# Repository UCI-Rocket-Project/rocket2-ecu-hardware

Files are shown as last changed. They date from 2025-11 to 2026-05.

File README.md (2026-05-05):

# rocket2's Engine Control Unit (ECU)
Documenation for ECU is hosted with MKDocs: [Click Here](https://uci-rocket-project.github.io/rocket2-ecu-hardware/)
  
# CAD



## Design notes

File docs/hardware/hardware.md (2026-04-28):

# Hardware Interface
## Electrical Design & 6-Layer Stackup
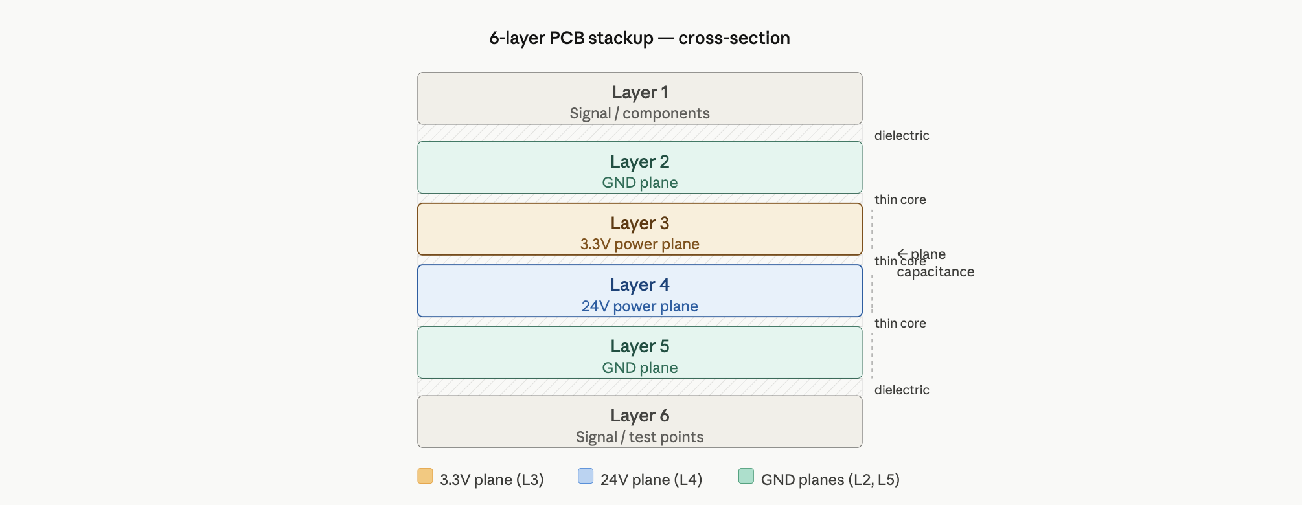
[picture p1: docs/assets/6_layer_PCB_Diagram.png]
ECU Stackup Diagram

*Figure 11: 6-Layer internal routing and power distribution stackup.*

| Layer | Type | Function |
| :--- | :--- | :--- |
| **L1** | Signal/GND | Component landing and logic routing. |
| **L2** | Ground | Solid internal Faraday cage for EMI shielding. |
| **L3** | 3.3V/Signal | Stabilized logic power plane. |
| **L4** | 24V/Signal | High-current propulsion power plane. |
| **L5** | Ground | Lower shielding plane for EM isolation. |
| **L6** | Signal/GND | Bottom-side debug access and telemetry routing. |

**Design :** The proximity of L3 (3.3V) and L4 (24V) to solid GND planes (L2, L5) creates high **inter-planar capacitance**. This acts as a distributed capacitor bank, preventing logic brownouts during high-current valve actuation.

---

## Connectors & Interconnect Board
The system architecture uses a vertical stack to balance high-density I/O with mechanical reliability.

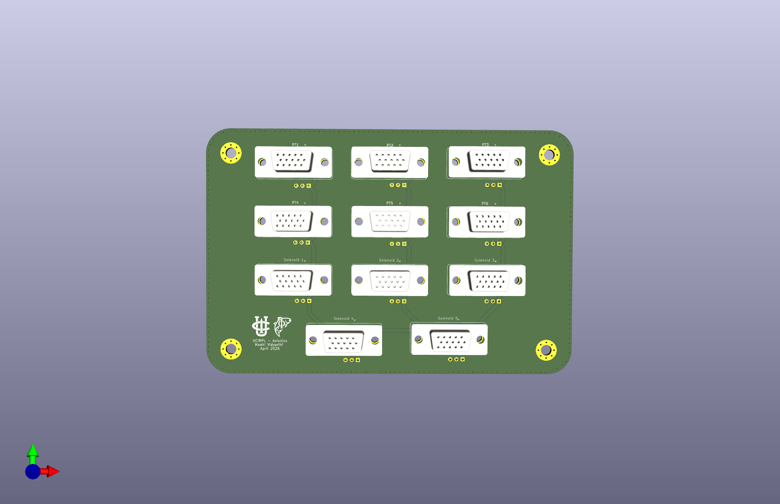
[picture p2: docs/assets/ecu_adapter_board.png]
ECU Adapter Board 3D Render

*Figure 12: 3D Render of the ECU Adapter Board.*

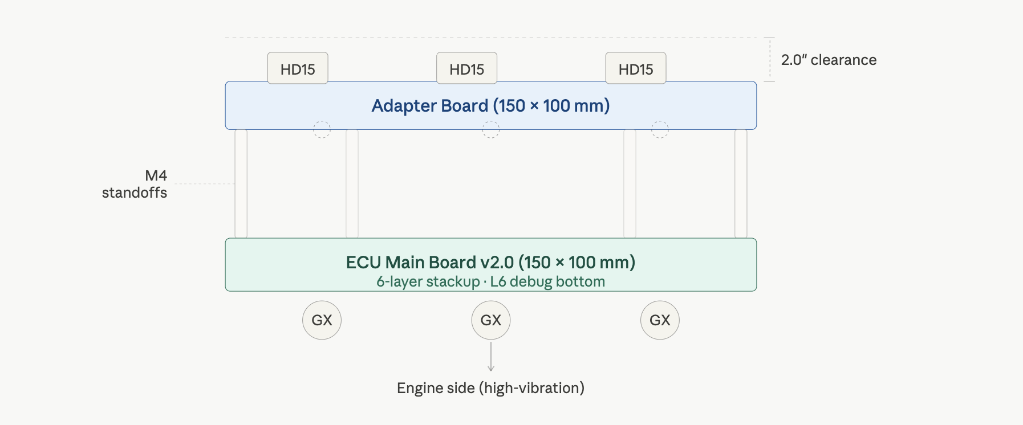
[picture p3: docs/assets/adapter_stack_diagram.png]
ECU Adapter Board 3D Render

*Figure 13: Diagram of the ECU Adapter Board stacking over the main ECU.*

### Transition Strategy: GX to HD15 (DSUB)
* **Main ECU Interface:** Uses **GX-series** circular connectors for high-vibration engine-side connections.
* **Adapter Board:** Stacks via standoffs to convert GX footprints to **HD15 (D-Sub)** for high-density signal distribution to the avionics tray.
* **Legacy Reference:** See [Legacy GX Wiring Documentation](https://github.com/maahividyarthi/ecu-adapter-boards/blob/main/docs/connectors_v1.md) for v1.0 compatibility.

### Mechanical Constraints
| Feature | Dimension | Notes |
| :--- | :--- | :--- |
| **Board Size** | 150mm x 100mm | Matches ECU v2.0 footprint. |
| **Mounting** | 4x M3 Holes | Standardized standoff pattern for vertical stacking. |
| **Max Stack Height**| 2.0" | Combined height of ECU + Standoffs + Adapter Board. |

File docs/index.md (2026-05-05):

# MOCH4 Engine Control Unit (ECU)

---

## System Overview
The Rocket2 ECU is the central flight hardware for the MOCH4 vehicle. It manages power distribution, sensor data acquisition, and valve actuation for the rocket's liquid propulsion system.

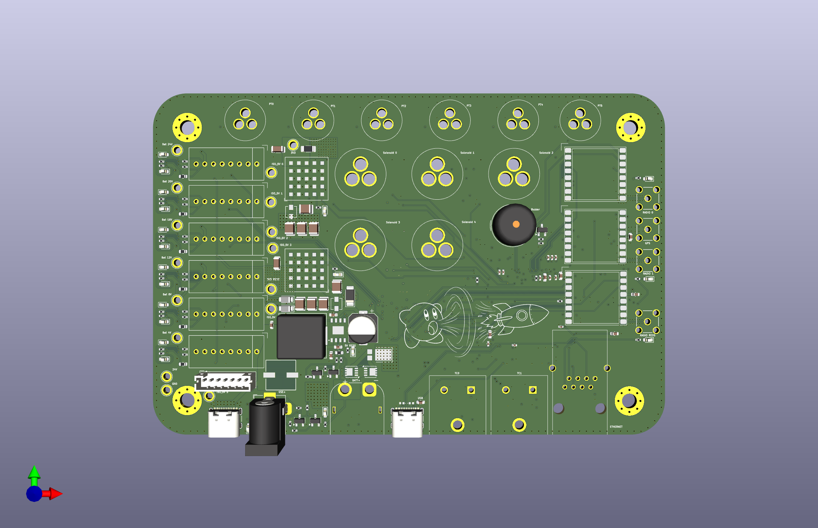
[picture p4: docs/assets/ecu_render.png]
Rocket2 ECU Render

*Figure 1: Top-down render of the Rocket2 ECU v2.0 PCB.*

## Stakeholders
* **AV - Hardware:** Reference for the [6-layer stackup](hardware/hardware.md) signal integrity, [JTAG debugging](bring_up/testplan.md) procedures, and general design logic/justifications.
* **AV - Software:** Mapping for SPI/I2C/UART buses and [STM32 pin assignments](logic/processing.md).
* **Propulsion:** Solenoid limits, actuation behavior, and sensor scaling  
- **Launch Vehicle:** [Mounting specifications](hardware/hardware.md), structural constraints, and connector access.

## Quick Specs
| Parameter | Value | Requirement Reference |
| :--- | :--- | :--- |
| **Input Voltage** | 24V DC | 24V Battery/GSE Requirement |
| **Battery Life** | > 4 Hours | System Operations Window |
| **Logic Level** | 3.3V | STM32 Standard |
| **Mounting Pattern** | 4x M3 holes with 3.2mm clearance | Avionics |
| **Dimensions** | 150mm x 100mm | Fits MOCH4 AV Bay |

## Hardware Architecture & Layout
To ensure flight reliability, the hardware follows a strict isolation and integration strategy:

* **6-Layer Stackup:** Dedicated ground planes (L2, L5) to shield logic (L3) from 24V power noise (L4)[cite: 617, 632]. See [Electrical Design](hardware/hardware.md).
* **Integrated Connectors:** DSUB Connector system implemented through [ECU Adapter Board](hardware/hardware.md) that stacks vertically to ECU, facilitating DSUB Connector to VGA Cable connection.
    * **Deprecated:** Standard HD15 and GX-series connectors are soldered directly to the board to eliminate wire-failure points.
* **Component Zoning:** The Battery Management System (BMS) and regulators are physically isolated on the left side, separated from RF antennas to minimize noise.
* **Accessibility:** All major test points and JTAG headers are accessible from the board's bottom side for post-integration debugging.

## Core Functionality
* **Propulsion:** 5 channels of high-side solenoid switching.
* **Instrumentation:** Dual-redundant [Pressure (PT)](sensors/sensors.md) and [Temperature (TC)](sensors/sensors.md) collection.
* **REDS:** [Emergency depressurization](power/battery_reds.md) capable of switching between Battery and GSE power.
* **Media:** Integrated charging for the onboard Insta360 camera.

## Debug & Failure Modes
* **Visual Feedback:** Onboard LEDs indicate 3.3V rail health and MCU heartbeat.
* **Alarm:** [Integrated siren](actuators/actuators.md) triggers on loss of GSE heartbeat or sensor failure (Note: **NOT IN USE**).
* **Safe State:** All solenoids default to CLOSED on power loss or MCU reset to prevent unintended propellant flow.

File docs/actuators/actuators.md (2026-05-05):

# Actuators & Alarms

## Solenoid Valve Drivers
The ECU features five independent high-side driver channels designed to actuate 24V propulsion solenoids (e.g., PeterPaul Series 20). 

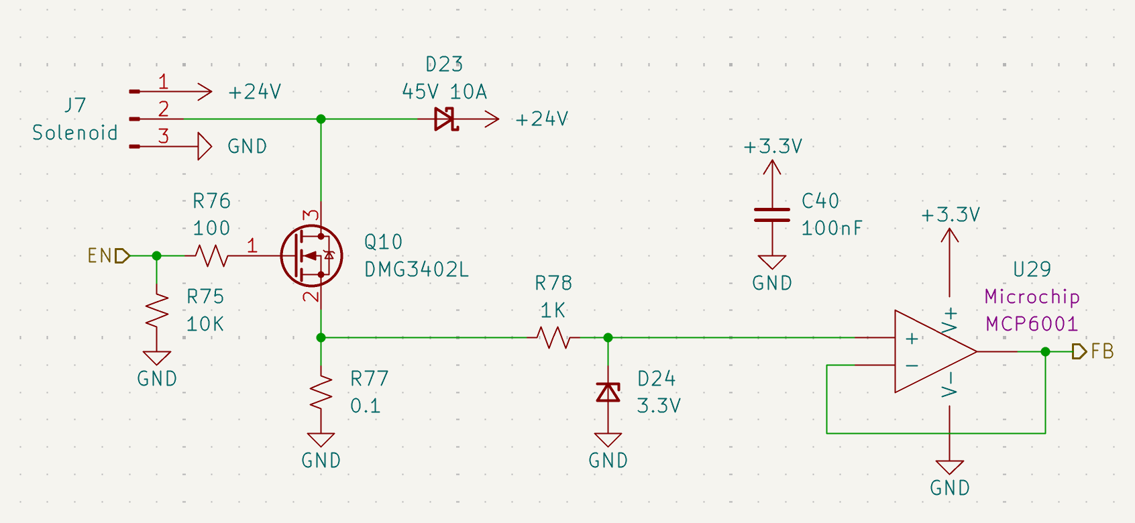
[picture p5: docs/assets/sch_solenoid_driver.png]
Schematic Snippet: Solenoid Driver

*Figure 20: High-side NMOS driver with integrated current feedback.*

### Driver Specifications
* **MOSFET:** [DMG3402L](https://www.diodes.com/assets/Datasheets/DMG3402L.pdf) (N-Channel).
* **Flyback Protection:** A **45V 10A** Schottky diode (**D23**) clamps inductive kickback from the valve coils to prevent rail transients.
* **Safety Logic:** A **10k&Omega;** pulldown resistor (**R75**) ensures the valve remains **CLOSED** if the MCU pin floats during boot or reset.

### Current Feedback (Health Monitoring)

Unlike v1.0, this revision provides active feedback to confirm solenoid actuation.

* **Shunt Resistor:** A **0.1&Omega;** precision resistor (**R77**) placed in the source path translates load current into a small voltage.
* **Protection:** A **3.3V Zener** (**D24**) clamps the feedback signal to protect the MCU ADC.
* **Active Buffer:** An **MCP6001** op-amp (**U29**) buffers the signal, allowing the firmware to distinguish between a healthy firing, an open-circuit (broken wire), or a short-circuit.

---

## Emergency Alarm System: Deprecated
The alarm circuit is designed to provide audible status alerts at the launchpad. 

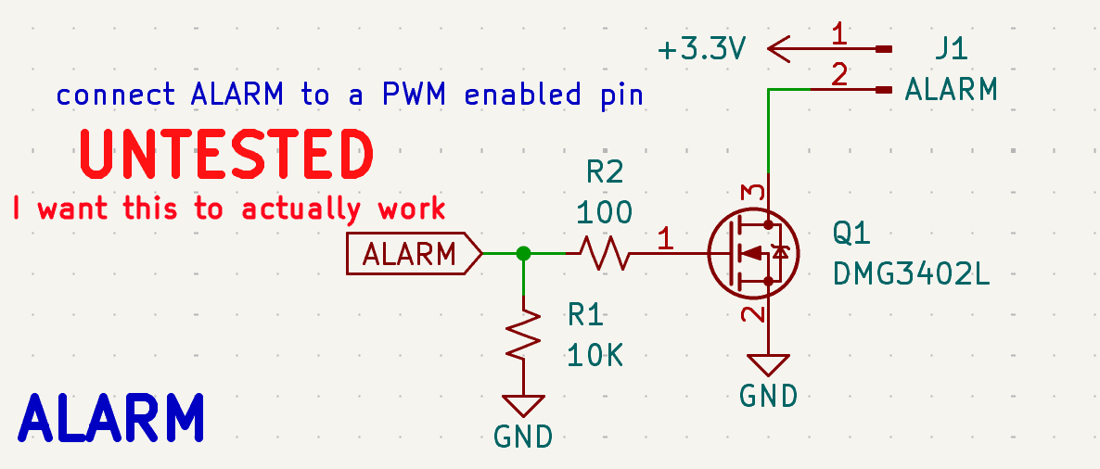
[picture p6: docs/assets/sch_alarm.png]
Schematic Snippet: Alarm Circuit

*Figure 21: Piezo/Siren driver circuit for audible telemetry.*

### Hardware Implementation
* **Driver:** **Q1** ([DMG3402L](https://www.diodes.com/assets/Datasheets/DMG3402L.pdf)) switches the low side of the **J1** alarm header.
* **Power Source:** Tied to the **+3.3V** logic rail.
* **Pin Assignment:** Connected to the **ALARM** net (**PE9**).

### Firmware Requirements (For "Actually Working")
To achieve the desired audible tones, the following software parameters must be met:
1. **PWM Frequency:** Must be tuned to the resonant frequency of the connected piezo (typically **2kHz - 4kHz**).
2. **Duty Cycle:** A **50% duty cycle** is recommended for maximum volume. 
3. **Timer Config:** Pin **PE9** must be configured in Timer Alternate Function mode to allow hardware PWM generation without CPU overhead.

---

## Integration Summary
| Channel | MCU Pin | Function | Notes |
| :--- | :--- | :--- | :--- |
| **SOL0** | PE13 | Vent Valve | NO (Normally Open) |
| **SOL1** | PE14 | Main Fuel | NC (Normally Closed) |
| **SOL2** | PE15 | Main LOX | NC (Normally Closed) |
| **ALARM** | PE9 | Piezo Siren | Deprecated |

**Operational Safety:** All propulsion solenoids are hardware-interlocked to the [REDS Recovery System](../power/battery_reds.md). In a total power loss scenario, the mechanical "Normal" state of the valve is the final fail-safe.

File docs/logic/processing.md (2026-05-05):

# STM32 Processing Core

## System Controller (STM32F469IIT6)
The Rocket2 ECU is powered by an ([STM32F469IIT6](https://www.st.com/resource/en/datasheet/stm32f469ii.pdf)) High-Performance MCU. This controller primarily coordinates sensor data with propulsion actuation logic.

### Power Supply & Decoupling Scheme
To ensure logic stability during high-current solenoid switching, the MCU utilizes an extensive decoupling network.

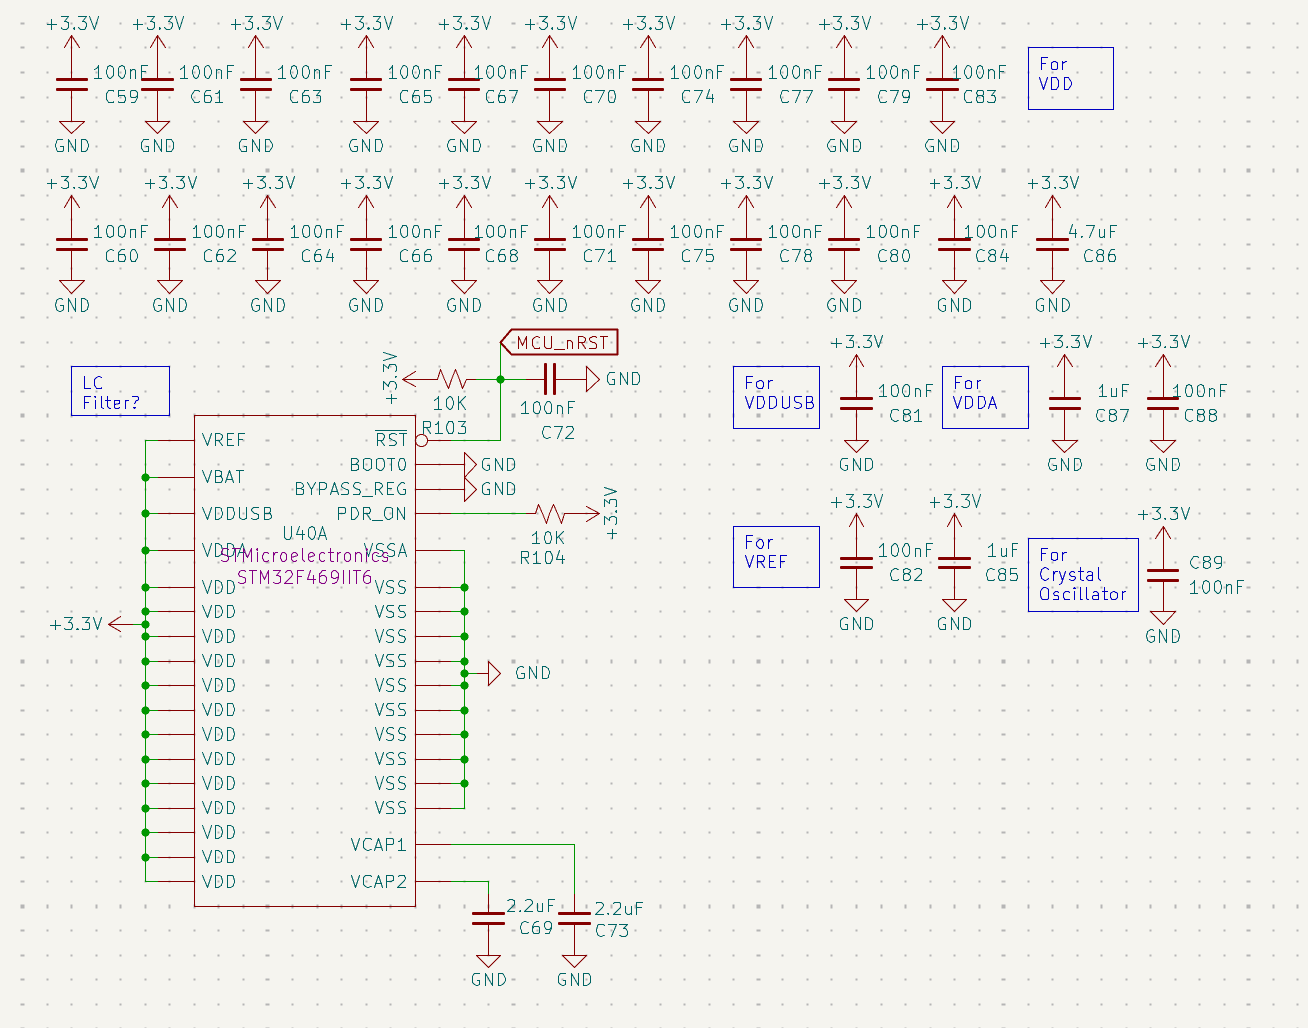
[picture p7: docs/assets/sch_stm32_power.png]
Schematic Snippet: Power Supply Scheme

*Figure 14: STM32 Power Scheme featuring localized 100nF and bulk 4.7&mu;F capacitors.*

* **Core Stability:** Localized **100nF** capacitors are placed at every VDD/VSS pair. 
* **Analog Integrity:** Dedicated decoupling for **VDDA** and **VREF** ensures high-fidelity ADC readings for propulsion and battery sensing.
* **Internal Regulation:** **2.2&mu;F** low-ESR capacitors (**C69, C73**) are utilized on the **VCAP1/VCAP2** pins to stabilize the internal 1.2V core voltage.

---

## Debug & Programming Interfaces
The board provides two primary methods for firmware deployment and real-time telemetry debugging.

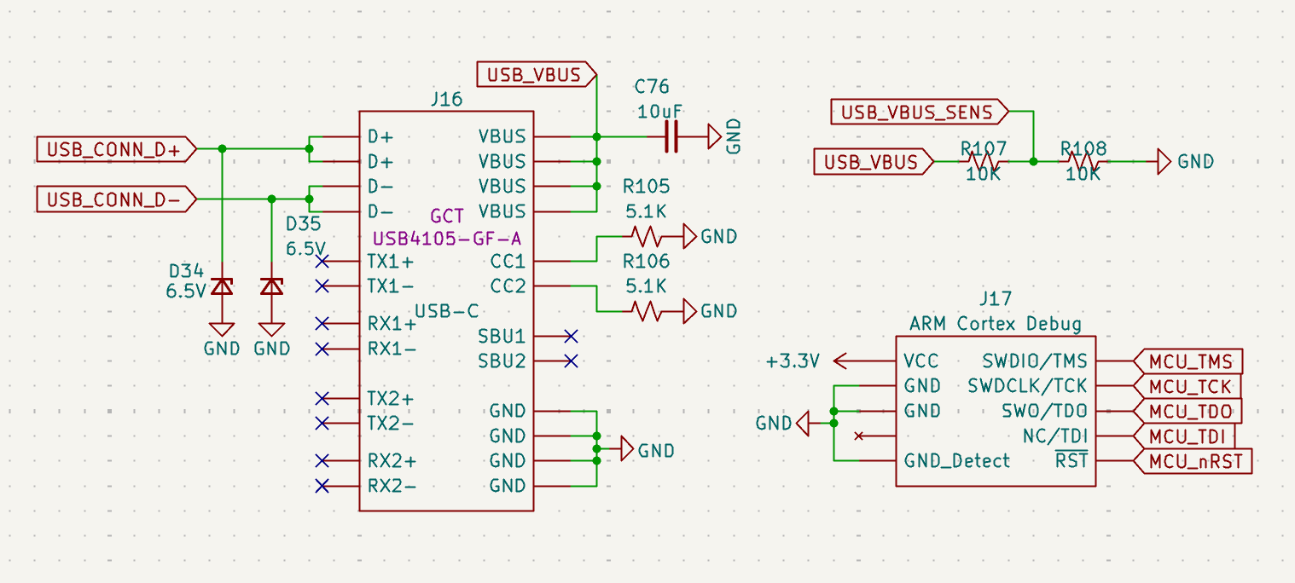
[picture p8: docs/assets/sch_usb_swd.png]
Schematic Snippet: USB-C and SWD

*Figure 15: USB-C interface and ARM Cortex 10-pin JTAG/SWD header.*

### SWD (Serial Wire Debug)
The **J17** header utilizes the standard **ARM Cortex 10-pin** (2x5) 1.27mm pitch layout.

* **Signals:** SWDIO, SWCLK, and SWO are routed for real-time instruction tracing.
* **Reset:** The **MCU_nRST** line is tied to a **100nF** capacitor (**C72**) and a **10k&Omega;** pull-up to prevent accidental resets from EMI.

### USB-C Interface
* **Model:** GCT USB4105-GF-A (16-pin).
* **Protection:** D34 and D35 (6.5V TVS diodes) protect the high-speed data lines from ESD during handling.
* **Sensing:** A voltage divider (**R107/R108**) on the **USB_VBUS_SENS** line allows the MCU to detect when a ground station is connected via USB.

---

## Peripheral Pin Mapping
The following table outlines the functional mapping of the MCU GPIOs. The detailed ioc file and firmware documentation will be in the rocket2-ecu-firmware repo.

| Peripheral Group | Pin | Signal Name | Function |
| :--- | :--- | :--- | :--- |
| **Actuation** | PE13-15, PG0-1 | `SOLENOID[0-4]_EN` | PWM/Logic Valve Drive |
| **Feedback** | PB0-2, PC4-5 | `SOLENOID[0-4]_FB` | Analog Current Sensing |
| **Instrumentation** | PC0-3, PA2 | `PT[1-5]` | Pressure Transducer Inputs |
| **BMS Status** | PD8-12 | `REDs_CH[0-4]` | Isolated Charging Status |
| **Telemetry** | PF0-PF9 | `RADIO[0-1]` | Dual-LoRa SPI/GPIO Bus |
| **Flight Sensors** | PG9-14 | `IMU_SPI6` | High-speed IMU Acquisition |
| **Status** | PG5 | `STATUS_LED` | Heartbeat LED (D36) |

---

## Flash Memory Architecture
The ECU features a dual-chip external storage configuration providing a total of **2GB (1Gb + 1Gb)** of non-volatile memory. This high-capacity array is dedicated to high-frequency data logging and state persistence during flight.

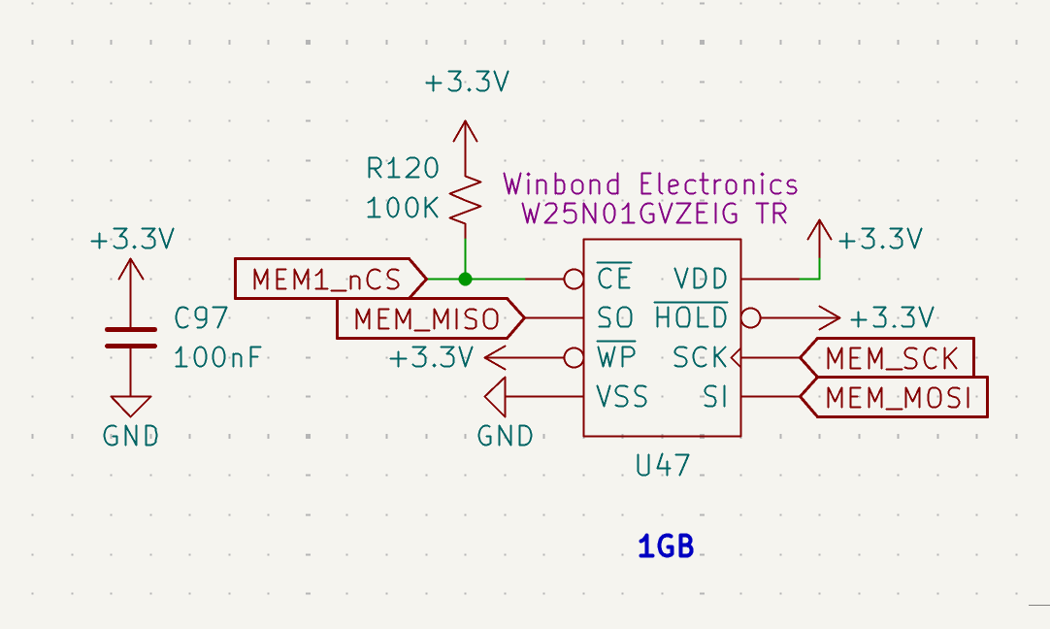
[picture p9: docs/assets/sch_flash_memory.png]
Schematic Snippet: Flash Memory Architecture

*Figure 16: Winbond W25N01G High-Performance Serial NAND Flash interface.*

* **Model:** [Winbond W25N01GVZEIG TR](https://www.winbond.com/resource-files/w25n01gv%20revl%20050918%20unsecured.pdf) (1G-bit / 128MB per chip).
### Hardware Configuration
* **Model:** Winbond **W25N01GVZEIG TR** (1G-bit / 128MB per chip).
* **Bus Interface:** Utilizes a high-speed **SPI** bus (`MEM_SCK`, `MEM_MISO`, `MEM_MOSI`).
* **Active-Low Select:** The chip-enable line (**MEM_nCS**) is tied to a **100k&Omega;** pull-up resistor (**R119**) to ensure the memory remains deselected during MCU reset, preventing data corruption.
* **Write Protection:** The **WP** (Write Protect) and **HOLD** pins are hardwired to **+3.3V** to allow continuous high-speed write access during flight.

### Data Logging Strategy
* **Total Capacity:** 2GB.
* **Throughput:** Optimized for the STM32's maximum SPI clock frequency to ensure that 100Hz+ sensor polling does not experience "blocking" during write cycles.
* **Decoupling:** Each IC is supported by a **100nF** decoupling capacitor (**C96**) placed immediately adjacent to the VDD pin to maintain signal integrity during high-speed switching.

---

### Fail-Safe Execution
* **Default States:** All solenoid enable pins are hardware-referenced to GND, ensuring valves remain in a safe/closed state during an MCU power loss or reset event.

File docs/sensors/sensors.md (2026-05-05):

# Sensors

## Flight Sensors
The ECU utilizes a multi-sensor architecture for real-time orientation and altitude tracking. 

| Sensor | Model | Bus | Range |
| :--- | :--- | :--- | :--- |
| **IMU** | [BMI088](https://www.bosch-sensortec.com/media/boschsensortec/downloads/datasheets/bst-bmi088-ds001.pdf) | SPI | ±24g / ±2000°/s |
| **Magnetometer**| [BMM350](https://www.bosch-sensortec.com/media/boschsensortec/downloads/datasheets/bst-bmm350-ds001.pdf) | I2C |  ±2000μT |
| **Altimeter** | [MS5607](https://www.te.com/commerce/DocumentDelivery/DDEController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) | SPI | 10–1200 mbar |

### Magnetometer (BMM350)
The BMM350 replaces the deprecated BMM150. It provides improved resolution (0.1μT) and a higher max sampling rate (400Hz).

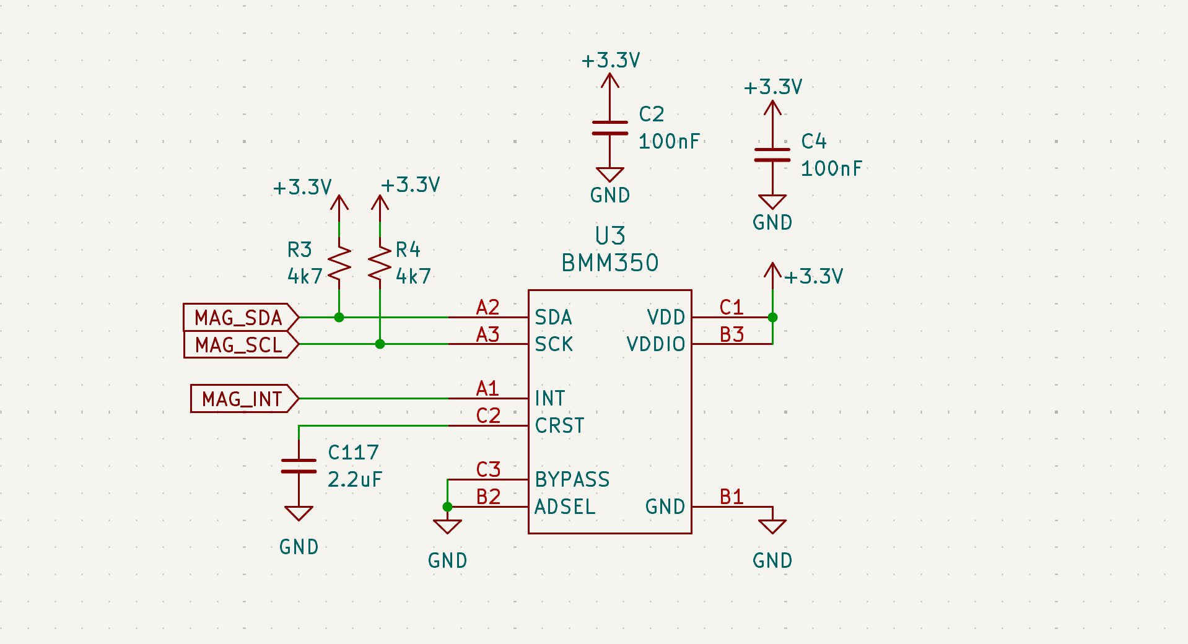
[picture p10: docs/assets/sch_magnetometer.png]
Schematic Snippet: Magnetometer

*Figure 23: BMM350 I2C interface with 4.7kΩ pull-up resistors (R3, R4).*

### IMU (BMI088)
Utilizes SPI for deterministic data acquisition. Provides ±24g acceleration range and ±2000°/s rate sensing.

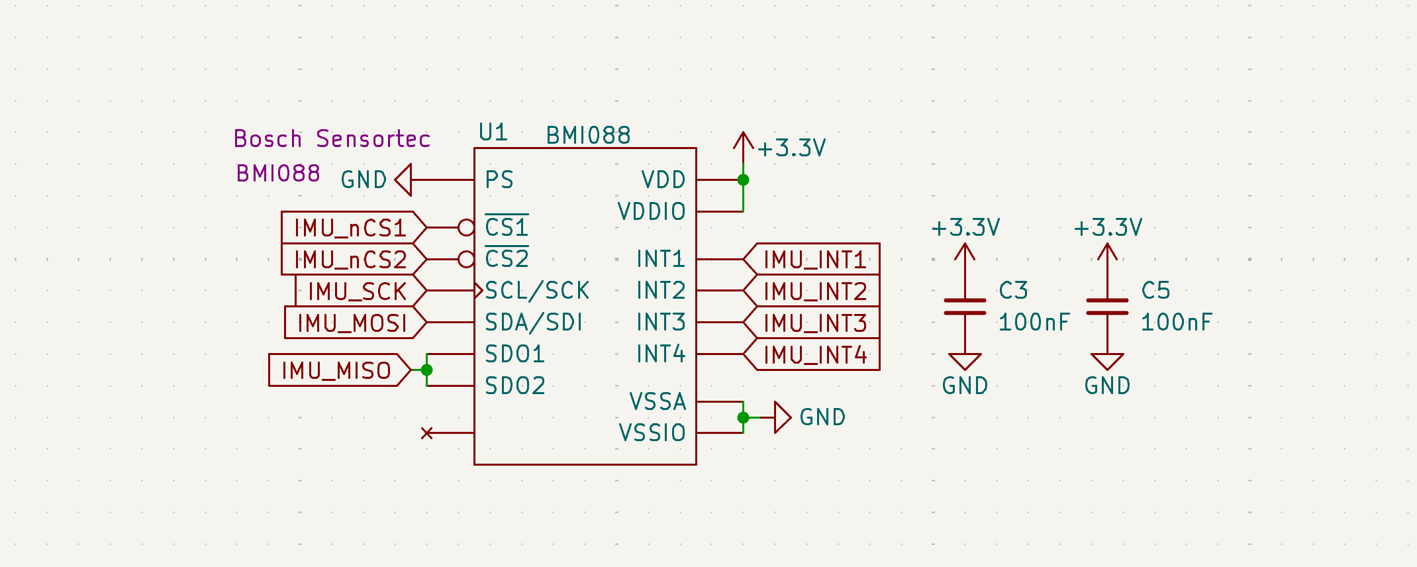
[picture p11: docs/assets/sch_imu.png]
Schematic Snippet: IMU

*Figure 24: BMI088 SPI interface with independent Accel and Gyro Chip Selects.*

### Altimeter (MS5607)
The Altimeter is connected via SPI, schematic attached below.

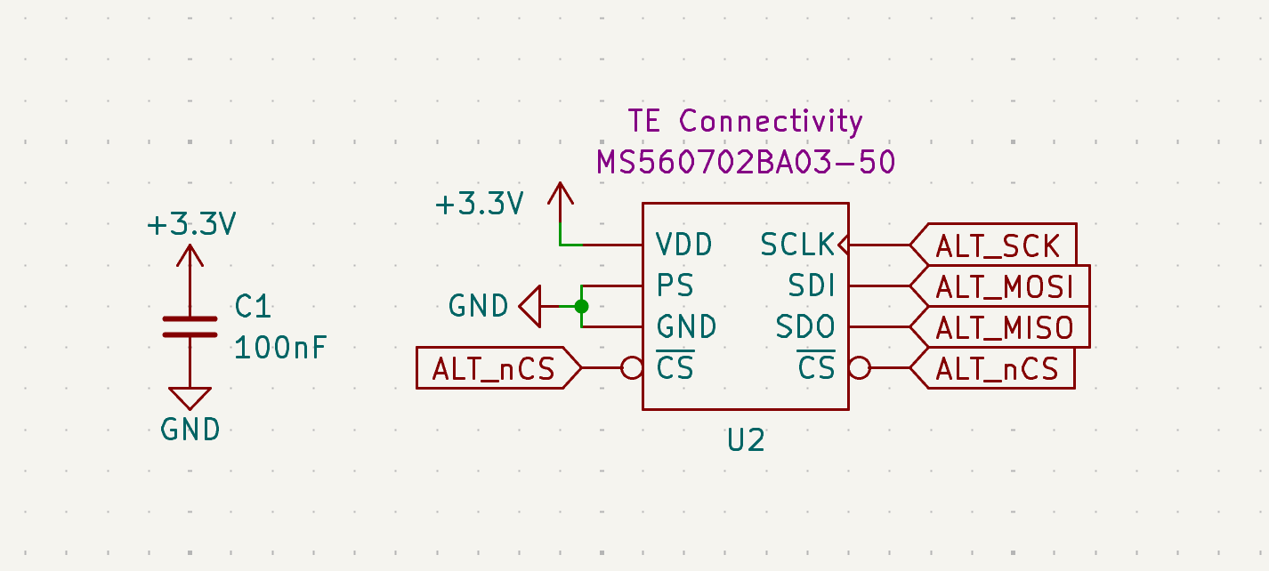
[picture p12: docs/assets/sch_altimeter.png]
Schematic Snippet: Altimeter

*Figure 25: MS5607 SPI interface with localized decoupling capacitors.*

---

## Propulsion Sensors
Propulsion sensors are subject to high EMI and vibration. Therefore, signal conditioning and filtering are critical for data integrity.

### Pressure Transducers (PT)
The PT circuit translates 0–5V analog signals from the transducer down to a 0–3.3V range suitable for the STM32 ADC.

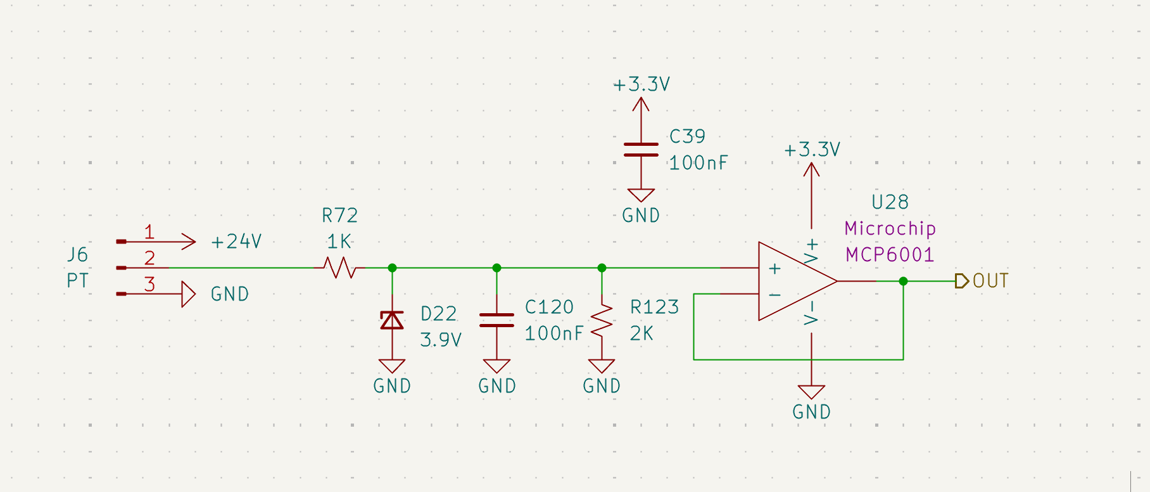
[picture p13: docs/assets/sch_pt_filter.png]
Schematic Snippet: PT Signal Conditioning

*Figure 26: PT conditioning stage featuring voltage clamping and active buffering.*

* **Sensor Model:** [Transducers Direct TDH40](https://transducersdirect.com/products/pressure-transducers/standard-pressure-transducers/tdh40-pressure-transducer-low-price-high-accuracy-volume-discount/)
* **Voltage Divider & Clamping:** A 1kΩ (**R72**) and 2kΩ (**R123**) divider scales the signal. A 3.9V Zener (**D22**) provides overvoltage protection.
* **Active Buffer:** An **MCP6001** op-amp (**U28**) provides a low-impedance input to the ADC to prevent sampling errors.
* **Noise Filtering:** An integrated RC lpf (**R72, C120**) provides a cutoff frequency of **1591 Hz** to reject high-frequency valve and engine noise.

### Thermocouples (TC)
Uses the **MAX31855JASA+** cold-junction compensated converter.

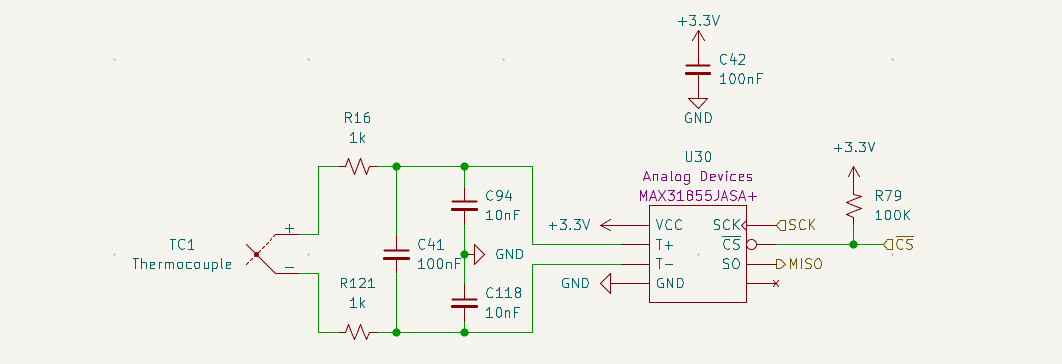
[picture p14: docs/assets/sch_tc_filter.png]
Schematic Snippet: Thermocouple Interface

*Figure 27: TC front-end with optimized differential and common-mode filtering.*

#### Filter Design & Justification
The TC front-end uses an optimized RC filter network to reject common-mode noise while maintaining a high signal-to-noise ratio (SNR). The design adheres to the **C<sub>diff</sub> > 10 &times; C<sub>cm</sub>** rule to minimize the impact of component tolerances on noise rejection.

| Parameter | Value | Formula / Calculation |
| :--- | :--- | :--- |
| **Series Resistance (R)** | 1 k&Omega; | R16, R121 |
| **Diff. Capacitance (C<sub>diff</sub>)** | 100 nF | C41 |
| **Common Mode Cap (C<sub>cm</sub>)** | 10 nF | C94, C118 |
| **Diff. Mode Cutoff (f<sub>c,dm</sub>)** | **~758 Hz** | 1 / (2&pi; &times; 2R &times; (C<sub>diff</sub> + C<sub>cm</sub>/2)) |
| **Common Mode Cutoff (f<sub>c,cm</sub>)** | **~15.9 kHz** | 1 / (2&pi; &times; R &times; C<sub>cm</sub>) |

* **Common Mode Rejection:** 10nF common-mode capacitors (**C94, C118**) reject noise that applies equally to both TC high and low voltages.
* **Sampling Sync:** The ~758Hz differential cutoff is specifically tuned to reject high-frequency engine noise while maintaining the 14Hz sampling resolution of the MAX31855.

---

### Integration & Cabling Note
As documented in the [Hardware Interface](../hardware/hardware.md), the connector system has been upgraded from direct-to-GX soldering to a standardized DSUB to VGA cable system. This system has been implemented for the ECU throught ECU Adaper Board, and will interface on the physical sensor end with a **Universal Adapter Board** system as described below. 

* **Sensor End:** PT/TC connects to a slot on the Universal Adapter Board.
* **Cable:** Standard VGA cables with **HD15 (D-Sub)** connectors are used for the main cable run.
* **ECU End:** Cable connects to the **ECU Adapter Board** stacked on the main ECU, completing the electrical path to the conditioned ADC pins.

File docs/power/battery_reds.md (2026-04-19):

# Battery & REDS 

## Overview
The **REDS** (Recovery Event Driver System) is a safety-critical power hub. It provides an isolated environment for 6-cell battery charging, precise rail monitoring via buffered dividers, and high-side switching for propulsion vent valves. 

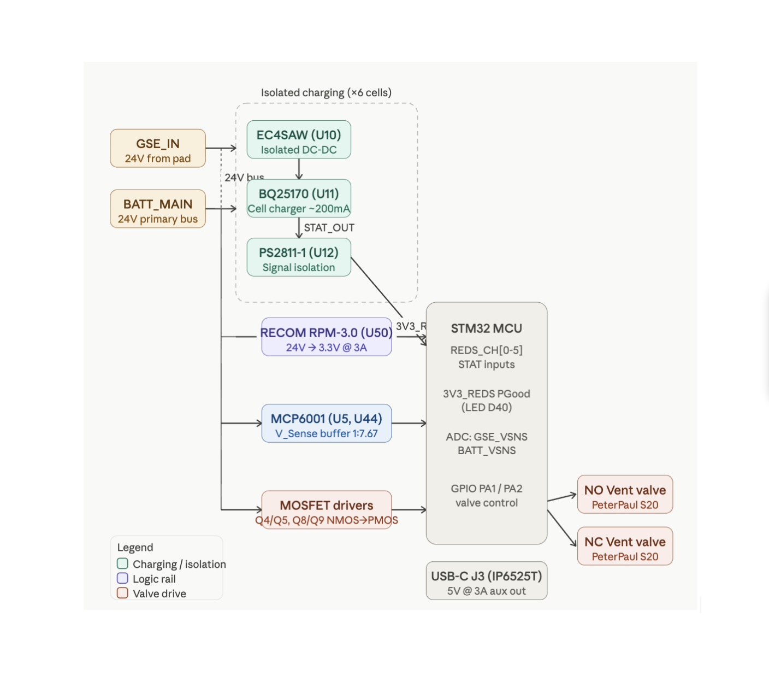
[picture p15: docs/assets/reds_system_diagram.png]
REDS System Architecture

*Figure 4: High-level block diagram of charging isolation and recovery logic.*

## Stakeholder Relevance
* **Avionics:** Critical facet of power on electronics; ensures logic survival during high-current events.
* **Propulsion:** Drive capacity for [PeterPaul Series 20](https://www.peterpaul.com/valves/2-way-normally-opened/series-20-model-21) (NO/NC) vent valves.
* **Operations:** Pre-launch camera power and battery health monitoring.

---

## Power System Reference
| Net Name | Source | Nominal Voltage | Max Current | Notes & Hardware Specs|
| :--- | :--- | :--- | :--- | :--- |
| **GSE+** | Ground pad | 24V | 5A* | External input used at pad. |
| **BATT_MAIN+** | 6S LiPo | 22.2V - 25.2V | — | Primary vehicle battery bus. |
| **GND** | Ground | 0V | — | Reference for ECU logic and valve returns. |
| **ISO_5V** | Cincon EC4SAW | 5V | 600mA | Isolated supply per charging block; floats relative to cell GND. |
| **ISO_GND** | Cincon EC4SAW | — | — | **Isolated return**; MUST NOT be shorted to System GND. |
| **3V3_REDS** | [RECOM RPM-3.0](https://www.recom-power.com/pdf/Innoline/RPM-6.0.pdf) | 3.3V | 3A | Independent logic rail; survives primary ECU bus failure. |
| **3V3_MAIN** | ECU Buck Reg | 3.3V | — | Primary logic rail for non-recovery ECU functions. |
| **GSE_VSNS** | [MCP6001](https://ww1.microchip.com/downloads/en/DeviceDoc/MCP6001-1R-1U-2-4-1-MHz-Low-Power-Op-Amp-DS20001733L.pdf) | 0&ndash;3.3V | — | Buffered ADC signal scaling GSE+ rail (1V:7.67V). |
| **BATT_VSNS** | [MCP6001](https://ww1.microchip.com/downloads/en/DeviceDoc/MCP6001-1R-1U-2-4-1-MHz-Low-Power-Op-Amp-DS20001733L.pdf) | 0&ndash;3.3V | — | Buffered ADC signal scaling BATT_MAIN+ (1V:7.67V). |
| **5V0_REDS** | [IP6525T](https://html.alldatasheet.com/html-pdf/1131972/INJOINIC/IP6525T/458/1/IP6525T.html) | 5V | 3A | Aux rail for Insta360; sourced from GSE+ via D3. |
| **STAT_OUT[0-5]** | [PS2811-1](http://www.vishay.com/docs/81753/vo615a.pdf) | 3.3V Logic | — | Isolated charge status (Active-Low) from BQ25170. |

## Design Details

### 1. Isolated Charging Architecture
To prevent ground loops and cell-balance shorts during charging, the system utilizes 6 independent charging blocks.

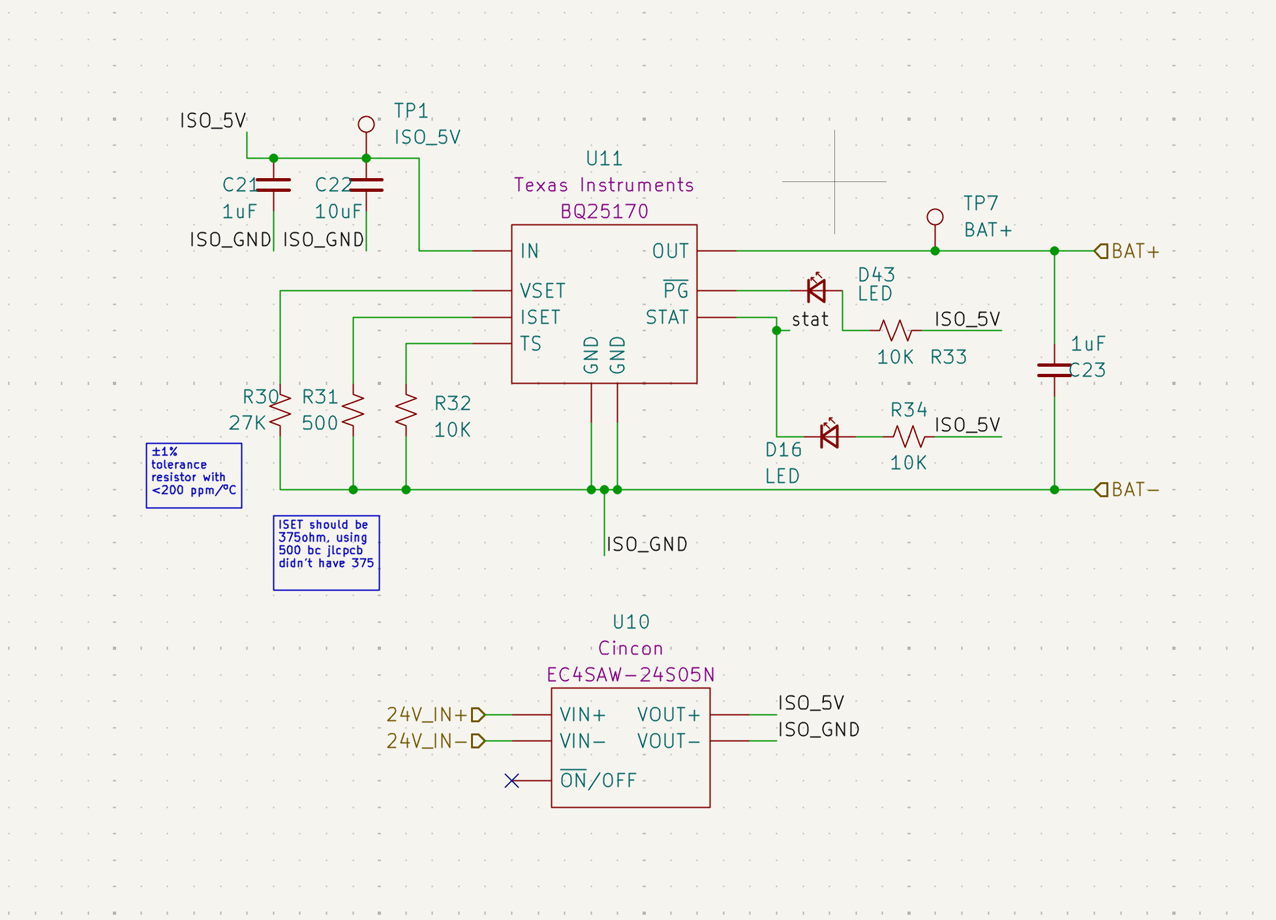
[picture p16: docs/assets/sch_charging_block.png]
Schematic Snippet: BQ25170 Charging Block

*Figure 5: Isolated charging stage showing Cincon DC-DC and BQ25170.*

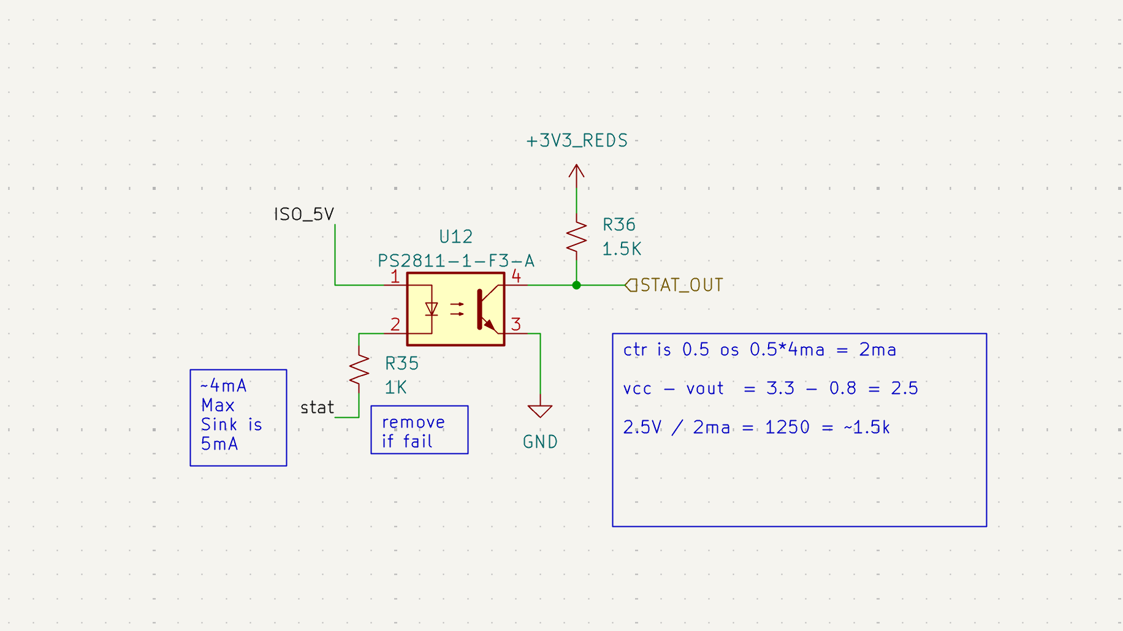
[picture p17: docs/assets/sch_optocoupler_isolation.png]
Schematic Snippet: Optocoupler Interface

*Figure 6: Isolated status feedback via PS2811-1 Optocouplers.*

* **Power Isolation:** Each cell uses a **Cincon EC4SAW (U10)** to decouple the GSE power from the specific battery cell potential.
* **Signal Isolation:** `STAT_OUT` signals use [PS2811-1](http://www.vishay.com/docs/81753/vo615a.pdf) optocouplers (U12) to cross the isolation barrier to the 3.3V logic rail. 
* **Design Deviation (ISET):** Target I_SET was 375 &Omega;. Current assembly uses **500 &Omega;** (&plusmn;1%, &lt;200 ppm/&ordm;C) due to availability, resulting in a slightly lower, safer charge rate for the [BQ25170](https://www.ti.com/product/BQ25170).

### 2. 3.3V_REDS Logic Rail
The `3V3_REDS` rail is independent of the main ECU 3.3V bus to ensure recovery capability  during bus failures.

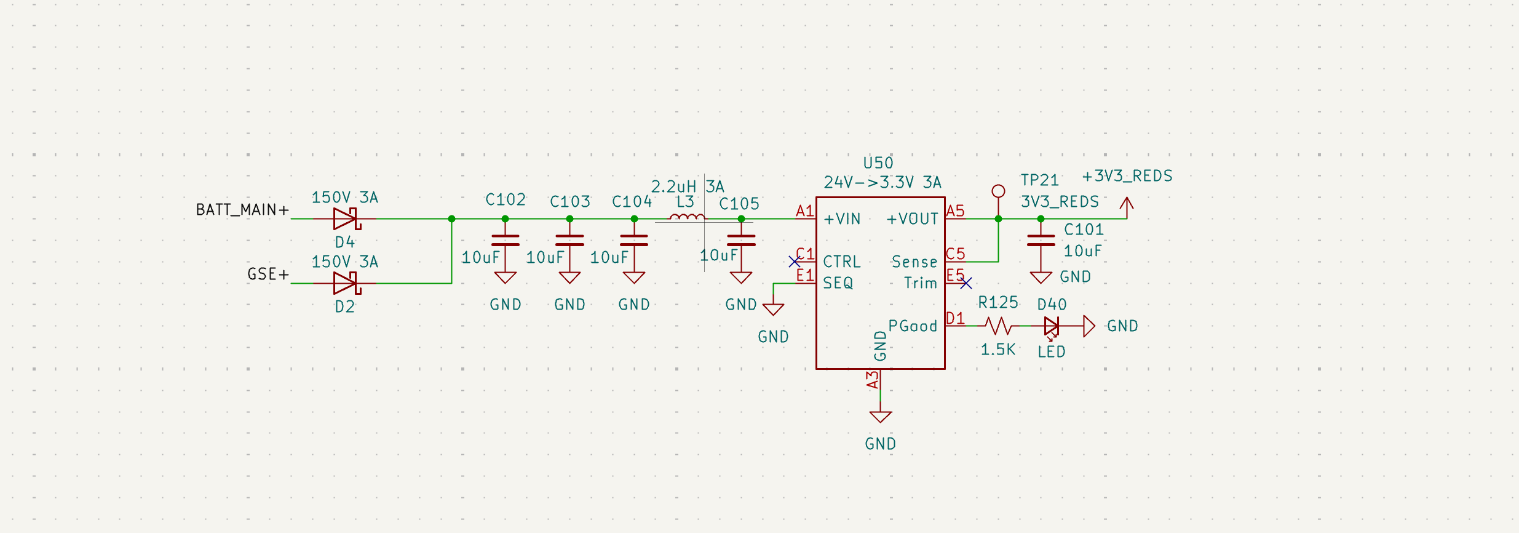
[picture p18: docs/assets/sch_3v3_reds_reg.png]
Schematic Snippet: U50 Regulator

*Figure 7: U50 RECOM regulator stage with input Pi-filter.*

* **Regulator:** **U50** ([RECOM RPM-3.0](https://www.recom-power.com/pdf/Innoline/RPM-6.0.pdf)) 24V to 3.3V.
* **Input Pi-Filter:** L3 (2.2 &mu;H) and C102-104. 
* **Thermal Note:** Inductor **L3** is rated for **3A**. While the RECOM module is robust, L3 is the primary thermal bottleneck if draw exceeds 3A.

### 3. Rail Voltage Sensing (MAIN & REDS)
The ECU employs two identical dual-stage sensing circuits to monitor the health of the 24V GSE and Battery rails for both the primary ECU (MAIN) and REDS.

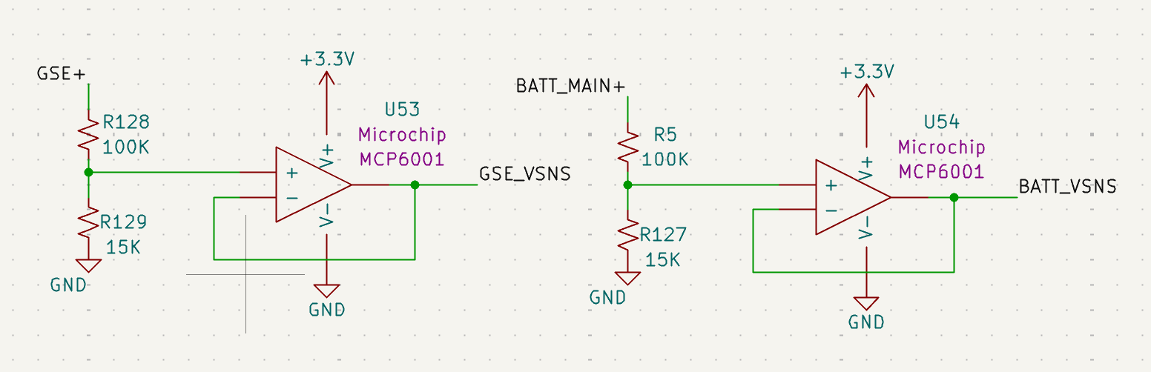
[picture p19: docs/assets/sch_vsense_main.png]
Schematic Snippet: V_Sense MAIN

*Figure 8: V_Sense MAIN buffers (U53/U54) monitoring primary power rails.*

* **Circuit Identity:** The REDS sensing stage (U5/U44) is topologically identical to the MAIN stage (U53/U54) shown above.
* **Precision Divider:** A 100 k&Omega; / 15 k&Omega; network provides a 1V : 7.67V scaling ratio.
* **High-Impedance Buffering:** [MCP6001](https://ww1.microchip.com/downloads/en/DeviceDoc/MCP6001-1R-1U-2-4-1-MHz-Low-Power-Op-Amp-DS20001733L.pdf) Op-amps are configured as voltage followers. This ensures that the sensing network does not load the battery and prevents ADC input impedance from introducing measurement error.
* **Component Requirement:** Resistors must be &plusmn;1% tolerance or better to ensure measurement accuracy across the flight temperature envelope.

### 4. Valve Drive Circuitry
The board features two high-side MOSFET driver channels (Q4/Q5 and Q8/Q9) designed to drive solenoids.

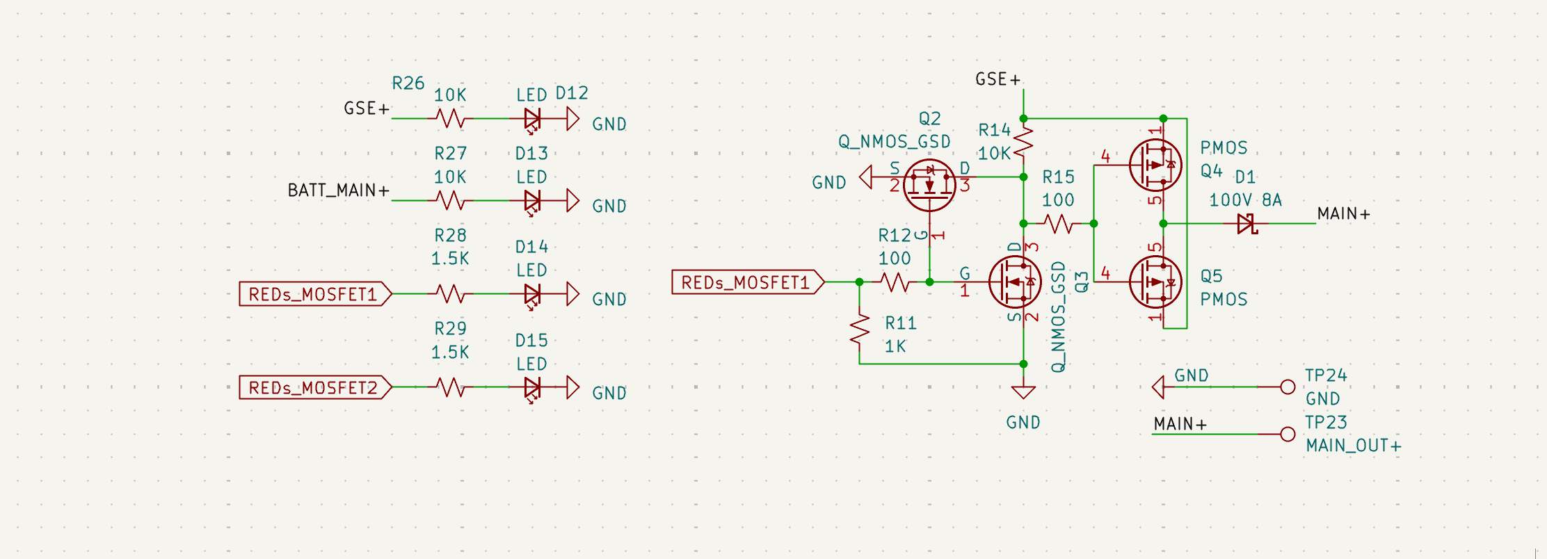
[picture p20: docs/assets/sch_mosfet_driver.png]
Schematic Snippet: MOSFET Drivers

*Figure 9: Typical NMOS-to-PMOS level shifting for 24V valve control (Channel 1 shown).*

* **Topology:** NMOS-to-PMOS level shifting (3.3V to 24V).
* **Flyback Protection:** Integrated 100V 8A Schottky diodes (D1, D7) clamp inductive spikes from solenoids.
* **Safety Logic:** NMOS pulldowns ensure valves remain in their "Normal" state if logic pins float.

### 5. Insta360 Camera 
A dedicated high-current 5V rail is provided for external peripherals, primarily the Insta360 flight camera.

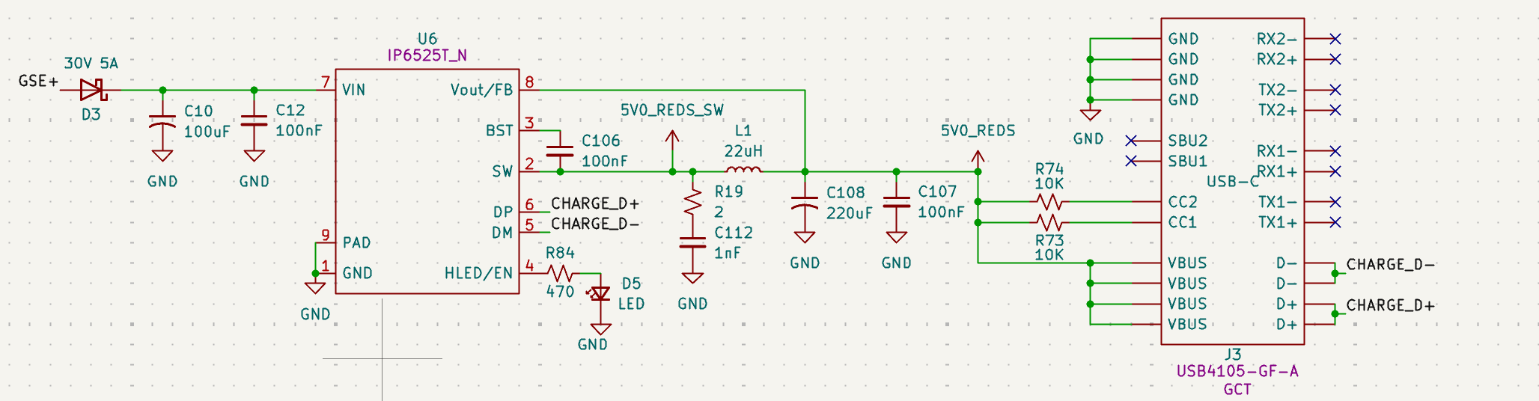
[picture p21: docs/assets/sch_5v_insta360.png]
Schematic Snippet: 5V 3A Insta360

*Figure 10: IP6525T Step-down converter for USB-C power delivery.*

* **Regulator:** **U6** ([IP6525T](https://html.alldatasheet.com/html-pdf/1131972/INJOINIC/IP6525T/458/1/IP6525T.html)) provides a stable 5V output at up to 3A.
* **Power Source:** This rail is tied to **GSE+** via a 30V 5A Schottky diode (**D3**). 
* **Ops Note:** Ops must verify the camera switches to internal battery smoothly during disconnect to ensure recording does not stop at T-0.
* **Filtering:** A 22 &mu;H inductor (**L1**) and a bulk 220 &mu;F capacitor (**C108**) minimize switching ripple to prevent video artifacts.
* **Indicator:** **LED D5** (Green) indicates the 5V Aux rail is active.

---

## Hardware&ndash;Software Interface

### Optocoupler Logic Calculation
The pull-up resistor (R36) for the `STAT_OUT` signal is **1.5 k&Omega;**.
* **CTR Calculation:** * V_{CC} - V_{OUT} = 3.3V - 0.8V = 2.5V
    * 2.5V / 2mA = 1250 &Omega; &approx; **1.5 k&Omega;**
* **Diagnostic:** If status signals fail to toggle, verify the optocoupler is driving at least 2mA.

## Errata / Revision Notes
* **Diode Corrected:** Fixed orientation of 30V 2A diode (reversed in v1.0).
* **ADC Simplification:** Deleted ADC from schematic for charge status; routed charging status to main ECU MC.

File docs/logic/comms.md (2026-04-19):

# Telemetry & Communications

## Dual LoRa Radio Modules (RFM95W)
The system utilizes two independent LoRa modules to provide long-range, low-power telemetry links at 915 MHz.

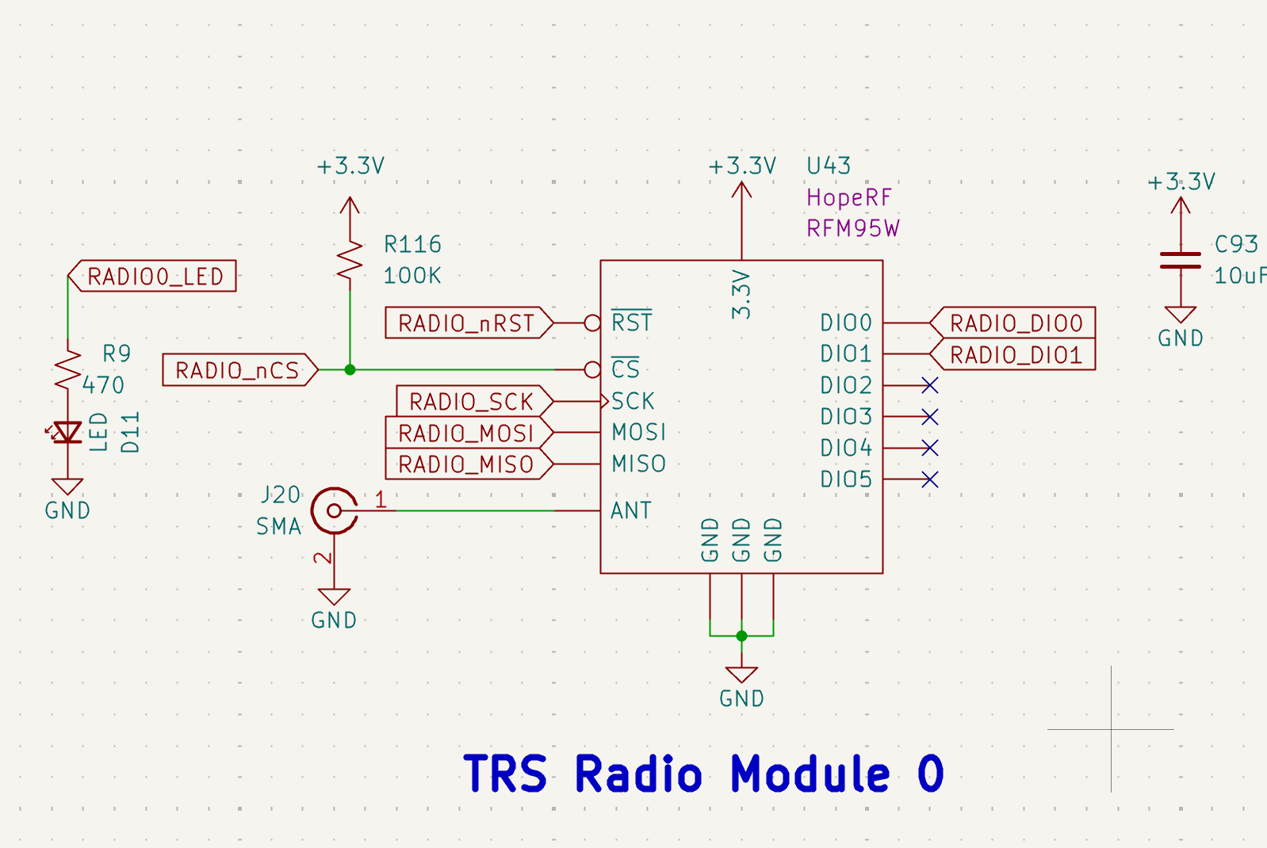
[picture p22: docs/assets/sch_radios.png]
Schematic Snippet: Dual Radio Modules

*Figure 17: Redundant TRS Radio Modules 0 and 1.*

* **Model:** [HopeRF RFM95W](https://cdn.sparkfun.com/assets/learn_tutorials/8/0/4/RFM95_96_97_98W.pdf).
* **Interface:** Connected via high-speed **SPI** with dedicated Chip Selects (**RADIO_nCS**, **RADIO1_nCS**).
* **Indicators:** Visual status is provided by **D11** and **D39** LEDs, which trigger during active packet transmission.
* **Antenna:** Standard 50&Omega; SMA connectors (**J20, J22**) are utilized for external dipole or whip antennas.
* **Design Defense:** Dual modules allow for frequency hopping or redundant data streams, ensuring telemetry persists even if one antenna path is compromised.

---

## GNSS Navigation (u-blox ZOE-M8Q)
For absolute positioning and time-synchronization, the ECU features a high-sensitivity u-blox GNSS module.

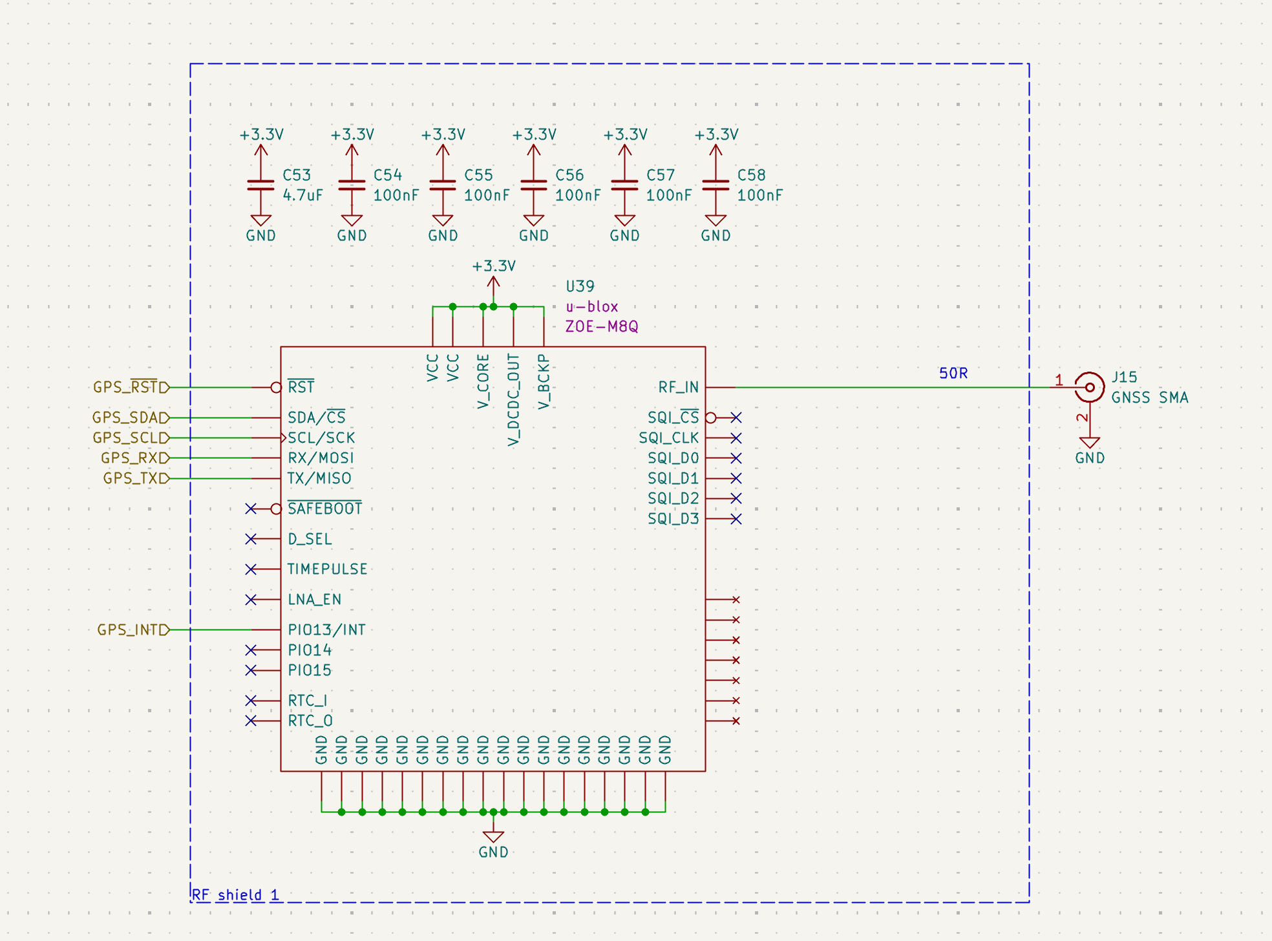
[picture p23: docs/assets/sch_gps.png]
Schematic Snippet: GPS/GNSS Module

*Figure 18: ZOE-M8Q implementation with RF shielding and active filtering.*

* **Model:** [u-blox ZOE-M8Q](https://content.u-blox.com/sites/default/files/ZOE-M8_DataSheet_UBX-16008094.pdf).
* **EMI Protection:** The module is housed within a dedicated **RF Shield** to prevent internal ECU logic noise from desensitizing the GPS receiver.
* **Interface:** Connected via **UART** (**GPS_RXD/TXD**) for standard NMEA sentence parsing.
* **Antenna:** Fed through a **50&Omega;** microstrip to an SMA connector (**J15**) for external active/passive GPS antennas.

---

## Ground-Test Ethernet (Grid Connect XPort)
A hardwired Ethernet interface is provided for high-bandwidth data offloading and ground station commanding during pad operations.

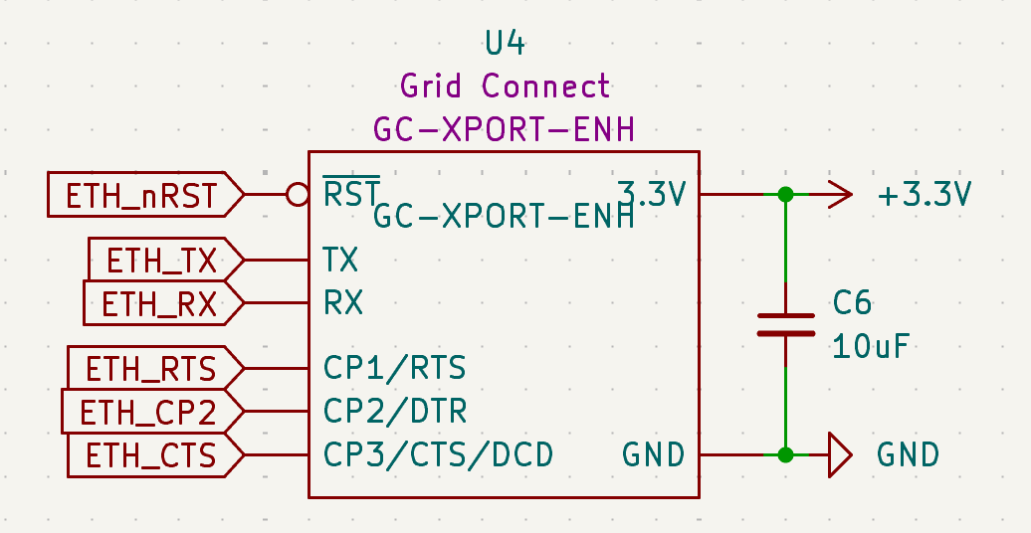
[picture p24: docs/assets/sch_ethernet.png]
Schematic Snippet: Ethernet Interface

*Figure 19: GC-XPORT-ENH Serial-to-Ethernet implementation.*

* **Model:** [Grid Connect GC-XPORT-ENH](https://gridconnect.box.com/shared/static/bu8k99agcgg8gspnja0ca8w7647gfghh.pdf).
* **Protocol:** Functions as a Serial-to-Ethernet bridge, allowing the STM32 to communicate over TCP/UDP via its internal USART interface.
* **Stability:** Utilizes a **10uF** decoupling capacitor (**C6**) to stabilize the 3.3V rail during high-speed data bursts.
* **Control:** The **ETH_nRST** line allows the MCU to power-cycle the module if a network hang is detected.

---

## Communication Fail-Safes
* **Independent Resets:** Both LoRa radios and the Ethernet module have discrete reset lines tied to the MCU, preventing single peripheral hang from locking the communication bus.
* **EMI Zoning:** All RF connectors (SMA) are positioned at the board edge, away from the 24V propulsion regulation zone, to maximize signal-to-noise ratio (SNR).

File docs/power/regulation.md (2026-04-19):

# Voltage Regulation

## Overview
The Rocket2 ECU uses a high-efficiency switching regulator to step down the 24V primary battery bus to a stable 3.3V logic rail. This rail powers the STM32, all onboard sensors, and communication modules.

Rocket2 Power Diagram
*Figure 2: Voltage Regulation System Diagram*

---

## Hardware Specifications
| Parameter | Value | Note |
| :--- | :--- | :--- |
| **Regulator (U7)** | [RECOM RPM6.0-3.3](https://recom-power.com/pdf/Innoline/RPM-6.0.pdf) | LGA Power Module |
| **Input Range** | 24V Nominal | Protected against transients |
| **Output Current**| 6.0A Max | Limited by L2 (3A) |
| **Switching Freq**| 500 kHz | RECOM RPM6.0-3.3 fixed frequency PWM |

## Connections & Interfaces
* **24VIN:** Primary power input sourced from the Battery/GSE bus via a dedicated barrel jack or XT60.
* **3.3V_out:** The regulated output of the U7 RECOM module.
* **Test Point (TP26):** Main 3.3V probe point located immediately after the inductor/capacitor stage.

---
## Regulator Schematic

Rocket2 Voltage Regulator Schematic
**Figure 3: Voltage Regulation: Schematic*

## Design Details
### Input Stage & Pi-Filter
* **24V Diodes:** Upgraded to 100V 8A Schottky diodes to prevent back-feeding and allow high-current supply for propulsion requirements.
* **Pi-Filter:** To block inductive noise, a filter is implemented using C11, C13, C109, C110 (10&micro;F each) and L2 (2.2&micro;H). 
    * *Note: L2 is 3A rated; if 6A logic draw is required, this component must be bypassed/upgraded.*

### Status & Control Logic
* **Visual Status:** LED D6 (Green) is tied to the `PGood` pin. It illuminates only when the 3.3V rail is stable (>90% of nominal).
* **Always-On Logic:** The `CTRL` pin (C1) is NC (No Connection), ensuring the regulator initializes immediately upon 24V application.

## Bringup, Failure Modes, & Debugging
* **Bringup:** Ensure R85 Isolation during testing. Confirm LED ON status prior to powering stm32.
* **Troubleshooting:** If LED D6 is Dim/Off --> remove R85, check resistance to GND.
* **Debugging:** Test Point (TP26): Main 3.3V probe point located immediately after the inductor/capacitor stage.

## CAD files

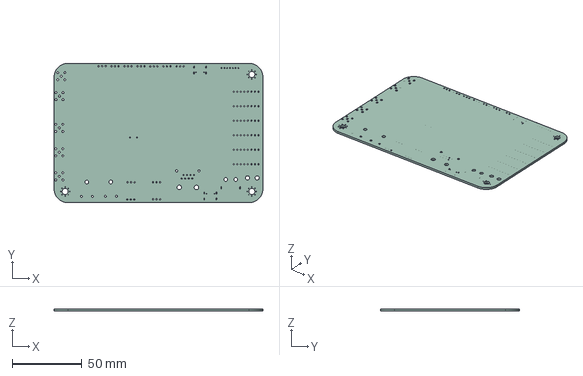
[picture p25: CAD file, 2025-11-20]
rocket2-ecu.step
150.0 x 100.0 x 1.51 mm

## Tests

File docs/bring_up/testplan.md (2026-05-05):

# ECU Hardware Bring-Up Test Plan

This page outlines the test plan for the ECU hardware from initially powering the board to firmware implementation.

---

## Note: Mandatory Testing Setup: Barrel Jack & GSE+
All circuits utilizing GSE+ as an input (including the 5V Insta360 regulator and the REDS Voltage Sense dividers) require the Barrel Jack connector to be populated and tested. Refer to schematic to ensure that the test can be conducted in a controlled manner please!

**Required Test Hardware:**
* Use a Barrel Jack-to-pigtail connector --> DC Jack to dual-wire Power/GND 
* Connect the wires to a DC Power Supply to do controlled voltage sweeps and current limiting!

---

## Power Subsystem Verification

### USB-C (Insta360) / 5V Regulator
*Note: Input sourced from GSE+ via Barrel Jack/D3.*

**Procedure:**

* Connect Anker power bank to USB-C (or bench supply via Barrel Jack). Or any other fast-charging USB-C item that can do the handshake! Power bank was used because it has a fast-charging (lightning indicator), but a safer option could include: 
* Confirm fast charging (LED status on board + lightning symbol on power bank).
* Monitor for excessive heat/smoke immediately after connection.
* Sweep Input Voltage: Start at 5V and increment to 24V using a DC power supply 

**Expected Voltages per Pin:**

| Pin | Expected Reading | Notes |
| :--- | :--- | :--- |
| **Vin** | Vin - &approx;0.5V | Accounting for diode forward voltage drop (D3). |
| **Vout** | 5.0V | Target regulated output. |
| **SW** | &approx; Average of Vin & GND | e.g., if Vin is 12V, SW should see &approx;5V-6V. |
| **BST** | SW + &approx;5.0V | If BST = SW, FET is not switching correctly. |

**Warning:** If BST is above or below 5V relative to the SW pin, the regulator circuit is non-functional.

### Six Single-Cell Chargers
**Procedure:**

* Solder all six single-cell charger ICs.
* **Visual Inspection:** Verify no bridges, lifted pads, or missing passives.
* **Input Sweep:** Using DC bench supply via Barrel Jack, sweep from 3.3V &rarr; 24V in 1V increments.
* **Monitoring:**
    * Measure 3.3V rail at each increment.
    * Monitor total input current draw.
    * Confirm blinking LEDs (indicates "no battery" state).
* **Load Test:** Connect a LiPo battery and verify charging current.

### Barrel Jack (AC Power / 24V)
**Procedure:**

* Connect 24V supply to barrel jack—**Verify polarity first**.
* Confirm 3.3V regulator output stability.
* Confirm all six single-cell chargers remain in the expected idle/standby state.
* **GSE Sense Check:** Verify voltage divider outputs at `REDs_V_SENSE1` match the 1V : 7.67V ratio.

---

## Firmware & Sensor Bring-Up

### Preliminary Checks

* Check for shorts across all data lines.
* Confirm resistance values match the schematic/BOM.
* Solder connectors onto the board prior to full firmware integration.

### Sensor Integration Order
Flash the test firmware and bring up the 3.3V rail to verify Ground Station communication.

* **IMU**: Initialize and verify raw data stream.
* **Altimeter**: Verify I2C/SPI address acknowledgement.
* **Magnetometer**: (Completed - Pending Review)
* **Flash Memory**: (Completed - Pending Review)
* **GPS**: Verify NEMA sentence reception.

### Peripheral Controls

* **PTs & TCs**: Analog front-end verification.
* **Solenoids**: Test firing with current limiting enabled.
* **Ethernet**:
    * Check hardware for shorts.
    * Initialize PHY in firmware (Verify Link LED).
    * Perform Ping test to Ground Station.

---

## General JTAG & Debugging Reference
*Note: Debugging interfaces are located on the **bottom layer (L6)**.*
Please **refer to schematic** for additional test points or connection clarification!!

### JTAG (J5) Pinout
| Pin | Signal | Pin | Signal |
| :--- | :--- | :--- | :--- |
| 1 | **3.3V (VREF)** | 2 | **SWDIO** |
| 3 | **GND** | 4 | **SWCLK** |
| 5 | **GND** | 6 | **SWO** |
| 7 | **KEY** | 8 | **NC** |
| 9 | **GND** | 10 | **nRESET** |

## Hardware Debug Log (April 2026)

### 5V Regulator Input Instability
* **Observations:**
    * Detected unstable resistance readings across the **Schottky diode (D3)** at the 5V regulator input.
    * **Reverse bias:** 1MΩ.
    * **Forward voltage:** 20v (likely faulty diode)
* **Steps Taken:**
    * Desoldered D3 and installed a jumper wire across the pads to bypass the diode for testing.
    * **Result:** Regulator circuit now displays stable, expected voltage values. 
    * **Validation:** Verified successful USBC handshake and fast-charging.
* **Next: May 2026:**
    * Parallel pathing for flashing **REDs firmware**.
    * Verifying **Ethernet communication** tests to verify Radio functionality and mirrored Main circuitry. 

### Issue: Balance Connector Mismatch
* Issue: balance connector currently on the board does not match the existing battery inventory.
* Solution Complete: Buy new batteries with the JST-style balance connector that maches the pcb footprint.

---

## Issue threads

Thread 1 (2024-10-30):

ECU Schematic Comments (Commit 74a4f86)

DanielHeEGG, 2024-10-30:
This review references commit 74a4f86f4d4766634681fad2ede5eb32b94be026

This is a high level review only. I did not check specific details (component value selection, orientation, footprint, label names, etc.) The design engineer is ultimately responsible for them.

## Solenoid, PT, TC
- Ok if designs are identical to current GSE designs, did not give detailed review

## REDS / Power
- Do we draw enough current to warrant a switching reg for 3V3?
- Recommend use both power sources for Insta360 charging
- USB-C port for Insta360 charging, 5V only no PD
- Assuming power switching related circuits have already been tested. **Please make sure the orientations are correct**

## Inertial Sensors
- Recommend moving away from Bosch sensors entirely (@RobertAWoo714 thoughts?)

## ECU Radios
- Why do we have 2 radios for ECU?

## GPS
- Recommend leaving nRST floating or open drain, or microcontroller will pull low and hard reset every time
- Recommend external crystal clock and backup battery
- RF shield not necessary, but ok
- **GPS_TX ISNT EVEN CONNECTED WTF**

Dat-Bois, 2024-10-31:
## Reds:
 - We draw an estimated peak ~300ma (the radio is most of it). Issue is mostly that any LDO kills itself due to thermals. I tested over Summer with a few different ones and even though its within spec, they can't operate for long enough and I no longer trust them.
 - I disagree with this since once GSE charges the battery past 24V the load will be put on the charging circuit which it is not rated for (Insta360 draws 5V/3A). What I am willing to do is once GSE is disconnected it can switch to battery power via mosfet, but I don't want in parallel.
 - I did USB-A for this so no one thinks they can plug their laptop or device in and since we don't have any PD negotiation it may not be safe. Also won't the insta360 try to negotiate power from PD if we do USB-C? Idk how that stuff works.
 - Yeah fixed this last time when we found the mosfet issue

## Inertial Sensors:
 - Ill wait for Robert's input on this

## ECU Radios:
 - We discussed this earlier that the ECU will have two separate 915mhz radios (Ryan will have more input on this).
 - REDs will have a single 433mhz

## GPS:
 - Will fix ✅
 - Sure, but will this even help for our usecase (once Rocket is on it stays on pretty much)
 - Shield looks cool hehehaha
 - Will fix ✅

DanielHeEGG, 2024-11-01:
## REDS
* ok
* ok use only ground power
* Use USB-C, PD negotiation is optional, 5V is default
* ok

## ECU Radios
* ok
* ok

## GPS
* ok
* Fine we don't need to bother
* fine
* ok

cadguyen, 2024-11-01:
From what I can see, **optocouplers** aren't going to be used to measure cell condition. Out of curiosity, what were your results from testing them?

RobertAWoo714, 2024-11-04:
## Intertial Sensors:
I got the Bosch sensors in a pretty useful circumstance where I don't see an issue coming that I haven't dealt with already. I'd keep them since we already wrote the drivers for them.
##LEDS
Recommend adding an LED for memory and GPS. Easiest way to troubleshoot/see if these sensors are working is to blink an LED whenever each component is done with a function.
##PTs and TCs
Lets add 2 extra PTs and 1 extra TC line just for any potential major fuck ups during VTF or coldflows. We already had a problem with the TC's SPI line getting confused during a cold flow, so lets try to be prepared for that.

Closed 2024-12-30.

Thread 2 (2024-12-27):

ECU Layout and Schematic Changes

Dat-Bois, 2024-12-27:
Just an issue tracker for the latest PCB layout as of 12/26/2024.

Layout
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

Layer Stackup:
 - Ground plane with signal traces (RED)
 - Primarily a ground plane with minimal traces (GREEN)
 - Power Plane +24V (post REDs) (ORANGE)
 - Power Plane +3.3V ECU, +3V3 REDS, +5V (NEON BLUE)
 - Primarily a ground plane with extremely minimal traces (PINK)
 - Ground plane with a lot of signal traces (DARK BLUE)

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

Parts layout:
 - ECU is primarily on the left side of the board
 - REDS is on the right
 - Power regulators and LoRa radios are underneath (flat components)
 - TCs + Solinoids on the bottom
 - PTs on the top

Potential issues:
 - Ethernet is in bottom right, based off images below unsure about wire bend radius (should be fine with a ribbon ethernet)
 - Similar for USB-C connectors. May need either ribbon or 90deg bend connectors.

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

Things to do:
 - Ground stitching as needed
 - Initial review by those on this issue thread

Dat-Bois, 2024-12-27:
Forgot the mounting holes. They have been adjusted to be about ~2mm closer to the edge of the board. Here is the hole pattern:

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

If the part it mounts to is already machined, we can 3d-print an adapter plate as needed (or I can really try squishing it).

DanielHeEGG, 2024-12-28:
The USB traces are quite long, consider impedance match 90R differential.
Avoid vias in pad, makes manufacturing difficult.
**GPS UART is reversed**
GPS I2C is not longer used, remove.
**ETHERNET UART is reversed**
@cadguyen please confirm alarm circuit removal.

USB traces on layer In1 interrupts continuous ground return of high current traces.
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

TC SPI traces on layer In1 interrupts continuous ground return high speed MEM SPI.
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

Do you really need to flood layer In2 with 24V? it seems to be useless on the left side of the board. Consider pouring 3.3V to increase current capacity for the radio modules.

Some silkscreen with basic version tracking & also labels would be helpful.

Just some initial thoughts. We'll do a full PDR start of winter.

Dat-Bois, 2024-12-30:
1. I'm not entirely sure how to do this within KiCad, is there a setting to make it 90ohm?. Also this will require impedance controlling the whole board for manufacturing right? Won't that be expensive?
2. Resolved, some pads still have vias but those pads are very large and shouldn't be an issue I think
3. Resolved
4. Resolved
5. Resolved
6. Still waiting on alarm confirmation
7-8. Not entirely sure what you mean by this, for both of them there is still an uninterrupted ground plane either below or above them. Does this mean something different?
9. Split In2 into 3 fills. 3.3V on left side of board, 24V in the middle with the power circuits, GND on the right-most near REDS
10. I'll add silkscreen and versioning at the very end once everything else is finalized since otherwise it makes things difficult to see.

Sounds good, @cadguyen do you think you can help me make the PDR document?

Dat-Bois, 2025-01-01:
Alarm removed and buzzer added 👍
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

Dat-Bois, 2025-01-07:
Resolved continuous ground issues (I think)

Dat-Bois, 2025-01-09:
Latest commit addresses some issues from PDR:
 - Fixed holes to be exactly 134mm x 84mm
 - GPS shield removed and moved closer to antenna
 - Reds Radio shifted to point towards the left side as well
 - Resolved vias in pads issues (as far as I can tell)

Dat-Bois, 2025-01-09:
Updates:
 - GS+ pad copper increased
 - Ground vias added and ground stiching done

Things Left:
 - Add GS/Batt voltage to ECU
 - Update IOC file
 - Update silkscreen

Dat-Bois, 2025-01-10:
All comments have been addressed:
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

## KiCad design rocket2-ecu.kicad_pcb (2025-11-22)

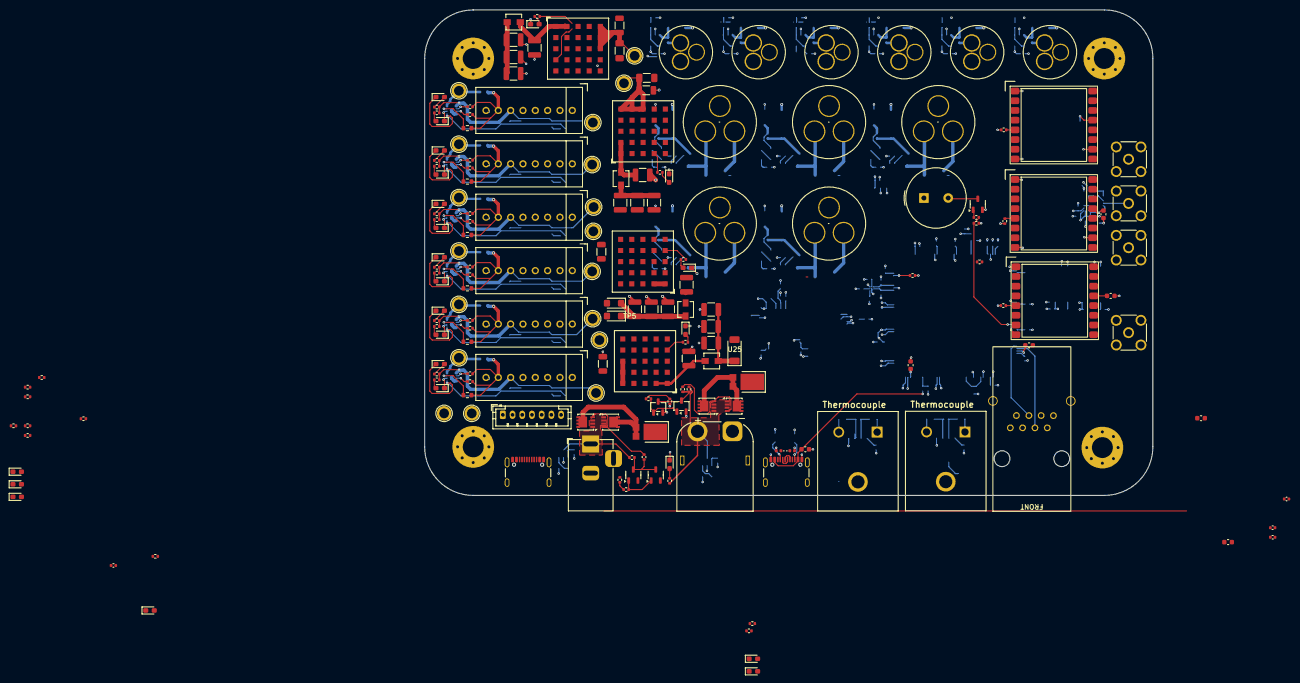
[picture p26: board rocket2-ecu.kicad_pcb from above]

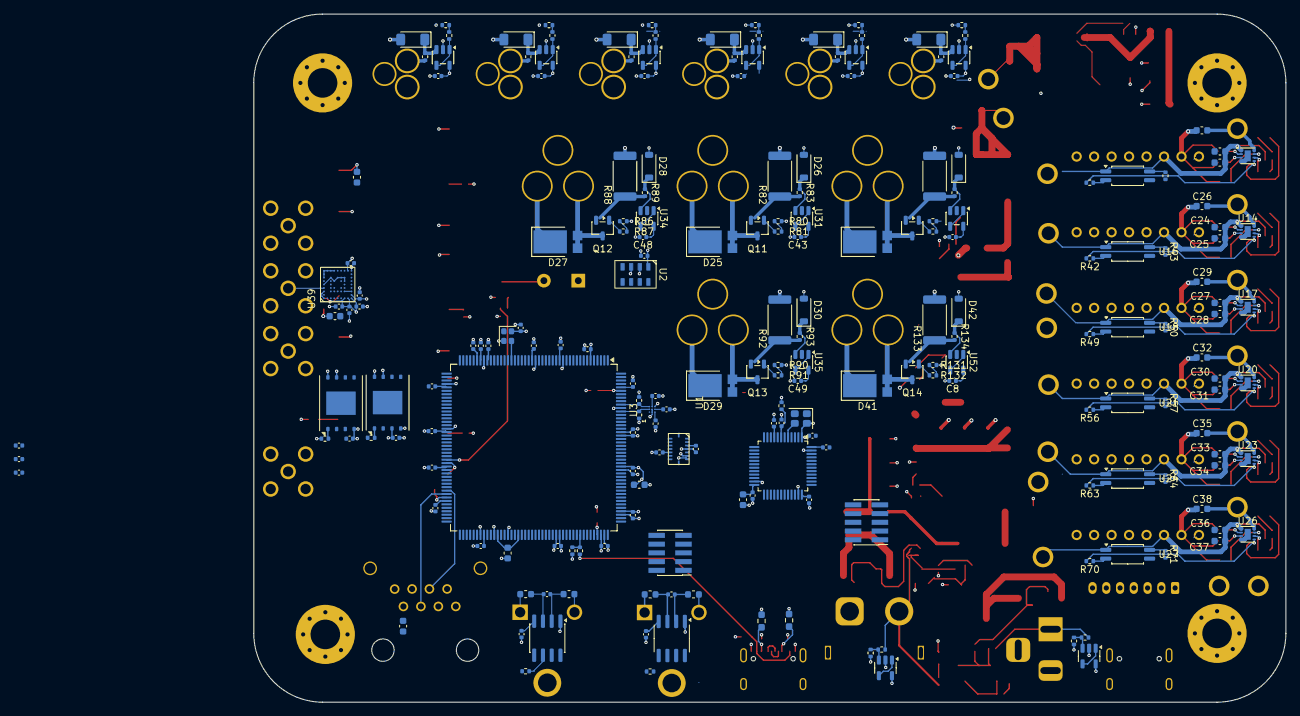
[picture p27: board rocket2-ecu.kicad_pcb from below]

Board: 6 copper layers, 150.0 x 100.0 mm, 403 parts (208 on the bottom side), 257 nets.

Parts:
C1, C2, C3, C4, C5, C8, C9, C15, C16, C17, C18, C19, C39, C40, C42, C43, C48, C49, C50, C51, C52, C54, C55, C56, C57, C58, C59, C60, C61, C62, C63, C64, C65, C66, C67, C68, C70, C71, C72, C74, C75, C77, C78, C79, C80, C81, C82, C83, C84, C88, C89, C91, C92, C96, C97, C100: 100nF; C_0402_1005Metric
C6, C20, C22, C25, C28, C31, C34, C37, C76, C93, C95: 10uF; C_0603_1608Metric
C10, C11, C12, C13, C102, C103, C104, C105, C106, C107, C109, C110, C112, C113, C114, C115: 10uF; C_1210_3225Metric
C14, C53, C86: 4.7uF; C_0603_1608Metric
C21, C23, C24, C26, C27, C29, C30, C32, C33, C35, C36, C38, C85, C87: 1uF; C_0603_1608Metric
C41, C99: 10nF; C_0402_1005Metric
C69, C73, C90: 2.2uF; C_0603_1608Metric
C101, C108, C111, C116: 10uF; C_1206_3216Metric
C117: 2.2uF; C_0402_1005Metric
D1, D7, D23, D25, D27, D29, D41: 100V 8A; D_PowerDI-5
D2, D4: 150V 3A; D_SMF
D3: 30V 5A; D_SOD-128
D5, D6, D8, D9, D10, D12, D13, D14, D15, D16, D17, D18, D19, D20, D21, D36, D40, D43, D44, D45, D46, D47, D48: LED; LED_0603_1608Metric_Pad1.05x0.95mm_HandSolder
D22, D31, D32, D33, D37, D38: 5.1V; D_MiniMELF
D24, D26, D28, D30, D42: 3.3V; D_SOD-123
D34, D35: 6.8V; D_0402_1005Metric
FB1, FB2, FB3, FB4: 470ohm @100MHz; L_0603_1608Metric
H1, H2, H3, H4: MountingHole_Pad; MountingHole_4.3mm_M4_Pad_Via
J1: ALARM; Buzzer_TDK_PS1240P02BT_D12.2mm_H6.5mm
J2: Conn_01x07; JST_PH_B7B-PH-K_1x07_P2.00mm_Vertical
J3, J16: USB-C; USB_C_Receptacle_GCT_USB4105-xx-A_16P_TopMnt_Horizontal
J4, J20, J22: SMA; SMA_Molex_73251-2200_Horizontal
J5, J17: ARM Cortex Debug; PinHeader_2x05_P1.27mm_Vertical_SMD
J6, J11, J12, J13, J18, J19: PT; GX-12 3 pin
J7, J8, J9, J10, J25: Solenoid; GX-16 3 pin
J14: Barrel_Jack_Switch; BarrelJack_Horizontal
J15: GNSS SMA; SMA_Molex_73251-2200_Horizontal
J24: XT60; AMASS_XT60PW-M_1x02_P7.20mm_Horizontal
L1, L2, L3, L4: 2.2uH 3A; L_Vishay_IHLP-1212
Q1, Q10, Q11, Q12, Q13, Q14: DMG3402L; SOT-23-3
Q2, Q3, Q6, Q7: Q_NMOS_GSD; SOT-23-3
Q4, Q5, Q8, Q9: PMOS; Vishay_PowerPAK_1212-8_Single
R1, R10, R14, R23, R26, R27, R32, R33, R34, R39, R40, R41, R46, R47, R48, R53, R54, R55, R60, R61, R62, R67, R68, R69, R74, R75, R80, R86, R90, R96, R99, R102, R103, R104, R107, R108, R112, R115, R131: 10K; R_0402_1005Metric
R2, R12, R15, R22, R24, R76, R81, R87, R91, R109, R132: 100; R_0402_1005Metric
R3, R4: 4k7; R_0402_1005Metric
R5, R9, R16, R25, R79, R116, R118, R119, R120, R124, R128: 100K; R_0402_1005Metric
R11, R20, R21, R35, R42, R49, R56, R63, R70, R72, R78, R83, R89, R93, R94, R97, R100, R110, R113, R130, R134: 1K; R_0402_1005Metric
R13, R18, R127, R129: 15K; R_0402_1005Metric
R17, R19, R28, R29, R36, R43, R50, R57, R64, R71, R125, R126: 1.5K; R_0402_1005Metric
R30, R37, R44, R51, R58, R65: 27K; R_0603_1608Metric
R31, R38, R45, R52, R59, R66: 375; R_0402_1005Metric
R73, R95, R98, R101, R111, R114: 5K; R_0402_1005Metric
R77, R82, R88, R92, R133: 0.1; R_2512_6332Metric
R84, R85: 0; R_1206_3216Metric_Pad1.30x1.75mm_HandSolder
R105, R106: 5.1K; R_0603_1608Metric_Pad0.98x0.95mm_HandSolder
TC1, TC2: Thermocouple; AM-K-PCB
TP1, TP2, TP3, TP4, TP5, TP6: ISO_5V; TestPoint_Plated_Hole_D2.0mm
TP7, TP8, TP9, TP10, TP11, TP12: BAT+; TestPoint_Plated_Hole_D2.0mm
TP21: 3V3_REDS; TestPoint_Plated_Hole_D2.0mm
TP22: 5V0_REDS; TestPoint_Plated_Hole_D2.0mm
TP23: MAIN_OUT+; TestPoint_Plated_Hole_D2.0mm
TP24: GND; TestPoint_Plated_Hole_D2.0mm
TP25: 5V; TestPoint_Plated_Hole_D2.0mm
TP26: 3.3V; TestPoint_Plated_Hole_D2.0mm
U1: BMI088
U2: MS560702BA03-50; MS5607-02BA
U3: BMM350
U4: GC-XPORT-ENH; GC-XPORT
U6, U51: 24V->5V 3A; Converter_DCDC_RECOM_RPMx.x-x.0
U7, U50: 24V->3.3V 3A; Converter_DCDC_RECOM_RPMx.x-x.0
U8: LQFP-48_7x7mm_P0.5mm
U9, U43, U45: RFM95W
U10, U13, U16, U19, U22, U25: EC4SAW-xxSxxN
U11, U14, U17, U20, U23, U26: WSON-8-1EP_2x2mm_P0.5mm_EP0.9x1.6mm
U12, U15, U18, U21, U24, U27: VOS615A-1; SOP-4_4.4x2.6mm_P1.27mm
U28, U29, U31, U34, U35, U36, U37, U38, U41, U42, U52, U53, U54: SOT-23-5
U30, U49: SOIC-8_3.9x4.9mm_P1.27mm
U39: ZOE-M8Q
U40: LQFP-176_24x24mm_P0.5mm
U46, U47: WSON-8-1EP_8x6mm_P1.27mm_EP3.4x4.3mm
Y1: 16MHz; Crystal_SMD_2520-4Pin_2.5x2.0mm
Y2: 16MHz; Crystal_SMD_2016-4Pin_2.0x1.6mm

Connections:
+3.3V: C1.1, C2.1, C3.1, C4.1, C5.1, C6.1, C8.1, C40.1, C42.1, C43.1, C48.1, C49.1, C53.1, C54.1, C55.1, C56.1, C57.1, C58.1, C59.2, C60.2, C61.2, C62.2, C63.2, C64.2, C65.2, C66.2, C67.2, C68.2, C70.2, C71.2, C74.2, C75.2, C77.2, C78.2, C79.2, C80.2, C81.2, C82.2, C83.2, C84.2, C85.2, C86.2, C87.2, C88.2, C89.1, C93.1, C95.1, C96.1, C97.1, C100.1, J1.1, J17.1 (VCC), R3.1, R4.1, R79.1, R85.2, R103.1, R104.2, R116.1, R118.1, R119.1, R120.1, R124.1, U1.3 (VDD), U1.11 (VDDIO), U2.1 (VDD), U3.B3 (VDDIO), U3.C1 (VDD), U4.2 (3.3V), U29.5 (V+), U30.4 (VCC), U31.5 (V+), U34.5 (V+), U35.5 (V+), U39.G1 (V_CORE), U39.H1 (V_DCDC_OUT), U39.H9 (V_BCKP), U39.J1 (VCC), U39.J2 (VCC), U40.6 (VBAT), U40.15 (VDD), U40.23 (VDD), U40.36 (VDD), U40.38 (VREF), U40.39 (VDDA), U40.49 (VDD), U40.62 (VDD), U40.72 (VDD), U40.82 (VDD), U40.96 (VDD), U40.118 (VDDUSB), U40.131 (VDD), U40.136 (VDD), U40.149 (VDD), U40.159 (VDD), U40.172 (VDD), U43.13 (3.3V), U45.13 (3.3V), U46.3 (~WP), U46.7 (~HOLD), U46.8 (VDD), U47.3 (~WP), U47.7 (~HOLD), U47.8 (VDD), U49.4 (VCC), U52.5 (V+), U53.5 (V+), U54.5 (V+), Y2.4
+3V3_REDS: C14.1, C15.1, C16.1, C17.1, C18.1, C19.1, C20.1, C101.1, J5.1 (VCC), R10.1, R25.1, R36.1, R43.1, R50.1, R57.1, R64.1, R71.1, TP21.1, U8.1 (VBAT), U8.9 (VDDA), U8.24 (VDD), U8.36 (VDD), U8.48 (VDD), U9.13 (3.3V), U50.A5 (+VOUT), U50.B5 (+VOUT), U50.C5 (Sense), Y1.4
+5V: C39.1, C50.1, C51.1, C52.1, C91.1, C92.1, R84.2, U28.5 (V+), U36.5 (V+), U37.5 (V+), U38.5 (V+), U41.5 (V+), U42.5 (V+)
+24V: C11.1, C13.1, C109.1, C112.1, C113.1, C114.1, D1.1 (K), D7.1 (K), D23.1 (K), D25.1 (K), D27.1 (K), D29.1 (K), D41.1 (K), J6.1, J7.1, J8.1, J9.1, J10.1, J11.1, J12.1, J13.1, J18.1, J19.1, J25.1, L2.1, L4.1, TP23.1
/BATT: D4.2 (A), J24.2, Q8.1 (S), Q8.2 (S), Q8.3 (S), Q9.1 (S), Q9.2 (S), Q9.3 (S), R5.1, R16.1, R23.1, R27.1
/GSE: D2.2 (A), D3.2 (A), J14.1, Q4.1 (S), Q4.2 (S), Q4.3 (S), Q5.1 (S), Q5.2 (S), Q5.3 (S), R9.1, R14.1, R26.1, R128.1, U10.2 (VIN+), U13.2 (VIN+), U16.2 (VIN+), U19.2 (VIN+), U22.2 (VIN+), U25.2 (VIN+)
/REDs/ALIVE_LED: R20.1, U8.45 (PB8)
/REDs/BATT_VSNS: U54.1, U54.4 (-)
/REDs/BAT_OUT+: C23.2, J2.1, TP7.1, U11.8 (OUT)
/REDs/GSE_VSNS: U53.1, U53.4 (-)
/REDs/MCU_TMS: J5.2 (SWDIO/TMS), U8.34 (PA13)
/REDs/RADIO_STATUS LED: R130.1, U8.18 (PB0)
/REDs/REDS_CH0: R36.2, U12.4
/REDs/REDS_CH1: R43.2, U15.4
/REDs/REDS_CH2: R50.2, U18.4
/REDs/REDS_CH3: R57.2, U21.4
/REDs/REDS_CH4: R64.2, U24.4
/REDs/REDS_CH5: R71.2, U27.4
/REDs/Single-Cell-Charger1/ISO_5V: C24.1, C25.1, R40.2, R41.2, TP2.1, U13.6 (VOUT+), U14.1 (IN), U15.1
/REDs/Single-Cell-Charger1/ISO_GND: C24.2, C25.2, C26.1, C29.2, R37.2, R38.1, R39.2, TP9.1, U13.7 (VOUT-), U14.4 (GND), U14.9 (GND), U17.8 (OUT)
/REDs/Single-Cell-Charger1/stat: D17.1 (K), R42.2, U14.5 (STAT)
/REDs/Single-Cell-Charger2/ISO_5V: C27.1, C28.1, R47.2, R48.2, TP3.1, U16.6 (VOUT+), U17.1 (IN), U18.1
/REDs/Single-Cell-Charger2/ISO_GND: C27.2, C28.2, C29.1, C32.2, J2.4, R44.2, R45.1, R46.2, TP10.1, U16.7 (VOUT-), U17.4 (GND), U17.9 (GND), U20.8 (OUT)
/REDs/Single-Cell-Charger2/stat: D18.1 (K), R49.2, U17.5 (STAT)
/REDs/Single-Cell-Charger3/ISO_5V: C30.1, C31.1, R54.2, R55.2, TP4.1, U19.6 (VOUT+), U20.1 (IN), U21.1
/REDs/Single-Cell-Charger3/ISO_GND: C30.2, C31.2, C32.1, C35.2, R51.2, R52.1, R53.2, TP11.1, U19.7 (VOUT-), U20.4 (GND), U20.9 (GND), U23.8 (OUT)
/REDs/Single-Cell-Charger3/stat: D19.1 (K), R56.2, U20.5 (STAT)
/REDs/Single-Cell-Charger4/ISO_5V: C33.1, C34.1, R61.2, R62.2, TP5.1, U22.6 (VOUT+), U23.1 (IN), U24.1
/REDs/Single-Cell-Charger4/ISO_GND: C33.2, C34.2, C35.1, C38.2, J2.6, R58.2, R59.1, R60.2, TP12.1, U22.7 (VOUT-), U23.4 (GND), U23.9 (GND), U26.8 (OUT)
/REDs/Single-Cell-Charger4/stat: D20.1 (K), R63.2, U23.5 (STAT)
/REDs/Single-Cell-Charger5/ISO_5V: C36.1, C37.1, R68.2, R69.2, TP6.1, U25.6 (VOUT+), U26.1 (IN), U27.1
/REDs/Single-Cell-Charger5/stat: D21.1 (K), R70.2, U26.5 (STAT)
/REDs/Single-Cell-Charger/ISO_5V: C21.1, C22.1, R33.2, R34.2, TP1.1, U10.6 (VOUT+), U11.1 (IN), U12.1
/REDs/Single-Cell-Charger/ISO_GND: C21.2, C22.2, C23.1, C26.2, J2.2, R30.2, R31.1, R32.2, TP8.1, U10.7 (VOUT-), U11.4 (GND), U11.9 (GND), U14.8 (OUT)
/REDs/Single-Cell-Charger/stat: D16.1 (K), R35.2, U11.5 (STAT)
ALARM: R1.2, R2.1, U40.70 (PE9)
ALT_MISO: U2.6 (SDO), U40.4 (PE5)
ALT_MOSI: U2.7 (SDI), U40.5 (PE6)
ALT_SCK: U2.8 (SCLK), U40.1 (PE2)
ALT_nCS: U2.4 (~CS), U2.5 (~CS), U40.2 (PE3)
ETH_CP2: U4.7 (CP2/DTR), U40.88 (PB15)
ETH_CTS: U4.8 (CP3/CTS/DCD), U40.86 (PB13)
ETH_RTS: U4.6 (CP1/RTS), U40.87 (PB14)
ETH_RX: U4.5 (RX), U40.79 (PB10)
ETH_TX: U4.4 (TX), U40.80 (PB11)
ETH_nRST: U4.3 (~RST), U40.85 (PB12)
GND: C1.2, C2.2, C3.2, C4.2, C5.2, C6.2, C8.2, C9.2, C10.2, C11.2, C12.2, C13.2, C14.2, C15.2, C16.2, C17.2, C18.2, C19.2, C20.2, C36.2, C37.2, C38.1, C39.2, C40.2, C42.2, C43.2, C48.2, C49.2, C50.2, C51.2, C52.2, C53.2, C54.2, C55.2, C56.2, C57.2, C58.2, C59.1, C60.1, C61.1, C62.1, C63.1, C64.1, C65.1, C66.1, C67.1, C68.1, C69.1, C70.1, C71.1, C72.2, C73.1, C74.1, C75.1, C76.2, C77.1, C78.1, C79.1, C80.1, C81.1, C82.1, C83.1, C84.1, C85.1, C86.1, C87.1, C88.1, C89.2, C90.1, C91.2, C92.2, C93.2, C95.2, C96.2, C97.2, C100.2, C101.2, C102.2, C103.2, C104.2, C105.2, C106.2, C107.2, C108.2, C109.2, C110.2, C111.2, C112.2, C113.2, C114.2, C115.2, C116.2, C117.2, D5.1 (K), D6.1 (K), D8.1 (K), D9.1 (K), D10.1 (K), D12.1 (K), D13.1 (K), D14.1 (K), D15.1 (K), D22.2 (A), D24.2 (A), D26.2 (A), D28.2 (A), D30.2 (A), D31.2 (A), D32.2 (A), D33.2 (A), D34.2 (A), D35.2 (A), D36.1 (K), D37.2 (A), D38.2 (A), D40.1 (K), D42.2 (A), J2.7, J3.A1 (GND), J3.A12 (GND), J3.B1 (GND), J3.B12 (GND), J4.2 (Ext), J5.3 (GND), J5.5 (GND), J5.9 (GND_Detect), J6.3, J7.3, J8.3, J9.3, J10.3, J11.3, J12.3, J13.3, J14.2, J14.3, J15.2 (Ext), J16.A1 (GND), J16.A12 (GND), J16.B1 (GND), J16.B12 (GND), J17.3 (GND), J17.5 (GND), J17.9 (GND_Detect), J18.3, J19.3, J20.2 (Ext), J22.2 (Ext), J24.1, J25.3, Q1.2 (S), Q2.2 (S), Q3.2 (S), Q6.2 (S), Q7.2 (S), R1.1, R11.1, R13.2, R18.2, R21.1, R65.2, R66.1, R67.2, R74.1, R75.1, R77.1, R80.1, R82.1, R86.1, R88.1, R90.1, R92.1, R96.1, R99.1, R102.1, R105.2, R106.2, R108.2, R112.1, R115.1, R127.2, R129.2, R131.1, R133.1, TP24.1, U1.4 (VSSA), U1.6 (VSSIO), U1.7 (PS), U2.2 (PS), U2.3 (GND), U3.B1 (GND), U3.B2 (ADSEL), U3.C3 (BYPASS), U4.1 (GND), U6.A3 (GND), U6.A4 (GND), U6.B1 (GND), U6.B2 (GND), U6.B3 (GND), U6.B4 (GND), U6.C2 (GND), U6.C3 (GND), U6.C4 (GND), U6.D2 (GND), U6.D3 (GND), U6.D4 (GND), U6.D5 (GND), U6.E1 (SEQ), U6.E3 (GND), U6.E4 (GND), U7.A3 (GND), U7.A4 (GND), U7.B1 (GND), U7.B2 (GND), U7.B3 (GND), U7.B4 (GND), U7.C2 (GND), U7.C3 (GND), U7.C4 (GND), U7.D2 (GND), U7.D3 (GND), U7.D4 (GND), U7.D5 (GND), U7.E1 (SEQ), U7.E3 (GND), U7.E4 (GND), U8.8 (VSSA), U8.23 (VSS), U8.35 (VSS), U8.44 (BOOT0), U8.47 (VSS), U9.1 (GND), U9.8 (GND), U9.10 (GND), U10.1 (VIN-), U12.3, U13.1 (VIN-), U15.3, U16.1 (VIN-), U18.3, U19.1 (VIN-), U21.3, U22.1 (VIN-), U24.3, U25.1 (VIN-), U25.7 (VOUT-), U26.4 (GND), U26.9 (GND), U27.3, U28.2 (V-), U29.2 (V-), U30.1 (GND), U31.2 (V-), U34.2 (V-), U35.2 (V-), U36.2 (V-), U37.2 (V-), U38.2 (V-), U39.A1 (GND), U39.A3 (GND), U39.A5 (GND), U39.A7 (GND), U39.A8 (GND), U39.A9 (GND), U39.B9 (GND), U39.C7 (GND), U39.C9 (GND), U39.D6 (GND), U39.D9 (GND), U39.E7 (GND), U39.F7 (GND), U39.G3 (GND), U39.G6 (GND), U39.G7 (GND), U39.J3 (GND), U39.J9 (GND), U40.14 (VSS), U40.22 (VSS), U40.37 (VSSA), U40.48 (BYPASS_REG), U40.61 (VSS), U40.71 (VSS), U40.95 (VSS), U40.99 (VDDDSI), U40.103 (VSSDSI), U40.109 (VSSDSI), U40.117 (VSS), U40.130 (VSS), U40.135 (VSS), U40.148 (VSS), U40.158 (VSS), U40.166 (BOOT0), U41.2 (V-), U42.2 (V-), U43.1 (GND), U43.8 (GND), U43.10 (GND), U45.1 (GND), U45.8 (GND), U45.10 (GND), U46.4 (VSS), U47.4 (VSS), U49.1 (GND), U50.A3 (GND), U50.A4 (GND), U50.B1 (GND), U50.B2 (GND), U50.B3 (GND), U50.B4 (GND), U50.C2 (GND), U50.C3 (GND), U50.C4 (GND), U50.D2 (GND), U50.D3 (GND), U50.D4 (GND), U50.D5 (GND), U50.E1 (SEQ), U50.E3 (GND), U50.E4 (GND), U51.A3 (GND), U51.A4 (GND), U51.B1 (GND), U51.B2 (GND), U51.B3 (GND), U51.B4 (GND), U51.C2 (GND), U51.C3 (GND), U51.C4 (GND), U51.D2 (GND), U51.D3 (GND), U51.D4 (GND), U51.D5 (GND), U51.E1 (SEQ), U51.E3 (GND), U51.E4 (GND), U52.2 (V-), U53.2 (V-), U54.2 (V-), Y1.2, Y2.2
GPS_INT: U39.G4 (PIO13/INT), U40.43 (PH2)
GPS_RX: U39.J4 (RX/MOSI), U40.40 (PA0)
GPS_TX: U39.J5 (TX/MISO), U40.41 (PA1)
IMU_INT1: U1.16 (INT1), U40.151 (PD7)
IMU_INT2: U1.1 (INT2), U40.152 (PG9)
IMU_INT3: U1.12 (INT3), U40.150 (PD6)
IMU_INT4: U1.13 (INT4), U40.147 (PD5)
IMU_MISO: U1.10 (SDO2), U1.15 (SDO1), U40.155 (PG12)
IMU_MOSI: U1.9 (SDA/SDI), U40.157 (PG14)
IMU_SCK: U1.8 (SCL/SCK), U40.156 (PG13)
IMU_nCS1: U1.14 (~CS1), U40.154 (PG11)
IMU_nCS2: U1.5 (~CS2), U40.153 (PG10)
MAG_INT: U3.A1 (INT), U40.164 (PB6)
MAG_SCL: R4.2, U3.A3 (SCK), U40.167 (PB8)
MAG_SDA: R3.2, U3.A2 (SDA), U40.165 (PB7)
MCU_TCK: J17.4 (SWDCLK/TCK), U40.137 (PA14)
MCU_TDI: J17.8 (NC/TDI), U40.138 (PA15)
MCU_TDO: J17.6 (SWO/TDO), U40.161 (PB3)
MCU_TMS: J17.2 (SWDIO/TMS), U40.128 (PA13)
MCU_nRST: C72.1, J17.10 (~RST), R103.2, U40.31 (~RST)
MEM1_nCS: R120.2, U40.59 (PF11), U47.1 (~CE)
MEM_MISO: U40.52 (PA6), U46.2 (SO), U47.2 (SO)
MEM_MOSI: U40.53 (PA7), U46.5 (SI), U47.5 (SI)
MEM_SCK: U40.51 (PA5), U46.6 (SCK), U47.6 (SCK)
MEM_nCS: R119.2, U40.44 (PH3), U46.1 (~CE)
unnamed: C105.1, L3.2, U50.A1 (+VIN), U50.A2 (+VIN)
unnamed: C107.1, L1.2, U6.A1 (+VIN), U6.A2 (+VIN)
unnamed: C110.1, L2.2, U7.A1 (+VIN), U7.A2 (+VIN)
unnamed: C115.1, L4.2, U51.A1 (+VIN), U51.A2 (+VIN)
unnamed: D1.2 (A), Q4.5 (D), Q5.5 (D)
unnamed: C102.1, C103.1, C104.1, D2.1 (K), D4.1 (K), L3.1
unnamed: C10.1, C12.1, C106.1, D3.1 (K), L1.1
unnamed: D5.2 (A), R19.2
unnamed: D6.2 (A), R17.2
unnamed: D7.2 (A), Q8.5 (D), Q9.5 (D)
unnamed: D8.2 (A), R126.2
unnamed: D9.2 (A), R130.2
unnamed: D10.2 (A), R20.2
unnamed: D12.2 (A), R26.2
unnamed: D13.2 (A), R27.2
unnamed: D14.2 (A), R28.2
unnamed: D15.2 (A), R29.2
unnamed: D16.2 (A), R34.1
unnamed: D17.2 (A), R41.1
unnamed: D18.2 (A), R48.1
unnamed: D19.2 (A), R55.1
unnamed: D20.2 (A), R62.1
unnamed: D21.2 (A), R69.1
unnamed: D22.1 (K), R72.2, U28.3 (+)
unnamed: D23.2 (A), J7.2, Q10.3 (D)
unnamed: D24.1 (K), R78.2, U29.3 (+)
unnamed: D25.2 (A), J8.2, Q11.3 (D)
unnamed: D26.1 (K), R83.2, U31.3 (+)
unnamed: D27.2 (A), J9.2, Q12.3 (D)
unnamed: D28.1 (K), R89.2, U34.3 (+)
unnamed: D29.2 (A), J10.2, Q13.3 (D)
unnamed: D30.1 (K), R93.2, U35.3 (+)
unnamed: D31.1 (K), R94.2, U36.3 (+)
unnamed: D32.1 (K), R97.2, U37.3 (+)
unnamed: D33.1 (K), R100.2, U38.3 (+)
unnamed: D36.2 (A), R109.1
unnamed: D37.1 (K), R110.2, U41.3 (+)
unnamed: D38.1 (K), R113.2, U42.3 (+)
unnamed: D40.2 (A), R125.2
unnamed: D41.2 (A), J25.2, Q14.3 (D)
unnamed: D42.1 (K), R134.2, U52.3 (+)
unnamed: D43.2 (A), R33.1
unnamed: D43.1 (K), U11.6 (~PG)
unnamed: D44.2 (A), R40.1
unnamed: D44.1 (K), U14.6 (~PG)
unnamed: D45.2 (A), R47.1
unnamed: D45.1 (K), U17.6 (~PG)
unnamed: D46.2 (A), R54.1
unnamed: D46.1 (K), U20.6 (~PG)
unnamed: D47.2 (A), R61.1
unnamed: D47.1 (K), U23.6 (~PG)
unnamed: D48.2 (A), R68.1
unnamed: D48.1 (K), U26.6 (~PG)
unnamed: J1.2, Q1.3 (D)
unnamed: J4.1 (In), U9.9 (ANT)
unnamed: J6.2, R72.1
unnamed: J11.2, R94.1
unnamed: J12.2, R97.1
unnamed: J13.2, R100.1
unnamed: J15.1 (In), U39.A4 (RF_IN)
unnamed: J16.A5 (CC1), R105.1
unnamed: J16.B5 (CC2), R106.1
unnamed: J18.2, R110.1
unnamed: J19.2, R113.1
unnamed: J20.1 (In), U43.9 (ANT)
unnamed: J22.1 (In), U45.9 (ANT)
unnamed: Q1.1 (G), R2.2
unnamed: Q2.3 (D), Q3.3 (D), R14.2, R15.1
unnamed: Q2.1 (G), Q3.1 (G), R12.2
unnamed: Q4.4 (G), Q5.4 (G), R15.2
unnamed: Q6.3 (D), Q7.3 (D), R23.2, R24.1
unnamed: Q6.1 (G), Q7.1 (G), R22.2
unnamed: Q8.4 (G), Q9.4 (G), R24.2
unnamed: Q10.1 (G), R76.2
unnamed: Q10.2 (S), R77.2, R78.1
unnamed: Q11.1 (G), R81.2
unnamed: Q11.2 (S), R82.2, R83.1
unnamed: Q12.1 (G), R87.2
unnamed: Q12.2 (S), R88.2, R89.1
unnamed: Q13.1 (G), R91.2
unnamed: Q13.2 (S), R92.2, R93.1
unnamed: Q14.1 (G), R132.2
unnamed: Q14.2 (S), R133.2, R134.1
unnamed: R35.1, U12.2
unnamed: R42.1, U15.2
unnamed: R49.1, U18.2
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

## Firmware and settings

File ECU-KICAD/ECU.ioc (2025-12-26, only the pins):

Mcu.UserName=STM32F469IITx
PA0/WKUP.GPIO_Label=GPS_TX
PA0/WKUP.Signal=UART4_TX
PA1.GPIO_Label=GPS_RX
PA1.Signal=UART4_RX
PA11.Signal=USB_OTG_FS_DM
PA12.Signal=USB_OTG_FS_DP
PA13.Signal=SYS_JTMS-SWDIO
PA14.Signal=SYS_JTCK-SWCLK
PA15.Signal=SYS_JTDI
PA2.GPIO_Label=PT5
PA2.Signal=ADCx_IN2
PA3.GPIO_Label=PT6
PA3.Signal=ADCx_IN3
PA4.GPIO_Label=ECU_BV
PA4.Signal=ADCx_IN4
PA5.GPIO_Label=MEM_SCK
PA5.Signal=SPI1_SCK
PA6.GPIO_Label=MEM_MISO
PA6.Signal=SPI1_MISO
PA7.GPIO_Label=MEM_MOSI
PA7.Signal=SPI1_MOSI
PA9.GPIO_Label=VBUS_SENS
PA9.Signal=USB_OTG_FS_VBUS
PB0.GPIO_Label=SOLENOID2_FB
PB0.Signal=GPIO_Input
PB1.GPIO_Label=SOLENOID3_FB
PB1.Signal=GPIO_Input
PB10.GPIO_Label=ETH_TX
PB10.Signal=USART3_TX
PB11.GPIO_Label=ETH_RX
PB11.Signal=USART3_RX
PB12.GPIO_Label=ETH_nRST
PB12.Signal=GPIO_Output
PB13.GPIO_Label=ETH_CTS
PB13.Signal=USART3_CTS
PB14.GPIO_Label=ETH_RTS
PB14.Signal=USART3_RTS
PB15.GPIO_Label=ETH_CP2
PB15.Signal=GPIO_Input
PB3.Signal=SYS_JTDO-SWO
PB6.GPIO_Label=MAG_INT
PB6.Signal=GPIO_Input
PB7.GPIO_Label=MAG_SDA
PB7.Signal=I2C1_SDA
PB8.GPIO_Label=MAG_SCL
PB8.Signal=I2C1_SCL
PC0.GPIO_Label=PT1
PC0.Signal=ADCx_IN10
PC1.GPIO_Label=PT2
PC1.Signal=ADCx_IN11
PC10.GPIO_Label=TC0_SCK
PC10.Signal=SPI3_SCK
PC11.GPIO_Label=TC0_MISO
PC11.Signal=SPI3_MISO
PC12.GPIO_Label=TC0_nCS
PC12.Signal=GPIO_Output
PC2.GPIO_Label=PT3
PC2.Signal=ADCx_IN12
PC3.GPIO_Label=PT4
PC3.Signal=ADCx_IN13
PC4.GPIO_Label=SOLENOID0_FB
PC4.Signal=GPIO_Input
PC5.GPIO_Label=SOLENOID1_FB
PC5.Signal=GPIO_Input
PD0.GPIO_Label=TC1_nCS
PD0.Signal=GPIO_Output
PD10.GPIO_Label=REDs_CH2
PD10.Signal=GPIO_Input
PD11.GPIO_Label=REDs_CH3
PD11.Signal=GPIO_Input
PD12.GPIO_Label=REDs_CH4
PD12.Signal=GPIO_Input
PD5.GPIO_Label=IMU_INT4
PD5.Signal=GPIO_Input
PD6.GPIO_Label=IMU_INT3
PD6.Signal=GPIO_Input
PD7.GPIO_Label=IMU_INT1
PD7.Signal=GPIO_Input
PD8.GPIO_Label=REDs-CH0
PD8.Signal=GPIO_Input
PD9.GPIO_Label=REDs_CH1
PD9.Signal=GPIO_Input
PE14.GPIO_Label=RADIO0_LED
PE14.Signal=GPIO_Output
PE15.GPIO_Label=RADIO1_LED
PE15.Signal=GPIO_Output
PE2.GPIO_Label=ALT_SCK
PE2.Signal=SPI4_SCK
PE3.GPIO_Label=ALT_nCS
PE3.Signal=GPIO_Output
PE5.GPIO_Label=ALT_MISO
PE5.Signal=SPI4_MISO
PE6.GPIO_Label=ALT_MOSI
PE6.Signal=SPI4_MOSI
PE9.GPIO_Label=ALARM
PE9.Signal=S_TIM1_CH1
PF0.GPIO_Label=RADIO_DIO1
PF0.Signal=GPIO_Input
PF1.GPIO_Label=RADIO_DIO0
PF1.Signal=GPIO_Input
PF10.GPIO_Label=PT0
PF10.Signal=ADC3_IN8
PF11.GPIO_Label=MEM1_nCS
PF11.Signal=GPIO_Output
PF13.GPIO_Label=SOLENOID0_EN
PF13.Signal=GPIO_Output
PF14.GPIO_Label=SOLENOID1_EN
PF14.Signal=GPIO_Output
PF15.GPIO_Label=SOLENOID2_EN
PF15.Signal=GPIO_Output
PF2.GPIO_Label=RADIO1_DIO1
PF2.Signal=GPIO_Input
PF3.GPIO_Label=ECU_GS
PF3.Signal=ADC3_IN9
PF4.GPIO_Label=RADIO1_nCS
PF4.Signal=GPIO_Output
PF5.GPIO_Label=RADIO1_nRST
PF5.Signal=GPIO_Output
PF6.GPIO_Label=RADIO_nCS
PF6.Signal=GPIO_Output
PF7.GPIO_Label=RADIO_SCK
PF7.Signal=SPI5_SCK
PF8.GPIO_Label=RADIO_MISO
PF8.Signal=SPI5_MISO
PF9.GPIO_Label=RADIO_MOSI
PF9.Signal=SPI5_MOSI
PG0.GPIO_Label=SOLENOID3_EN
PG0.Signal=GPIO_Input
PG1.GPIO_Label=SOLENOID4_EN
PG1.Signal=GPIO_Output
PG10.GPIO_Label=IMU_nCS2
PG10.Signal=GPIO_Output
PG11.GPIO_Label=IMU_nCS1
PG11.Signal=GPIO_Output
PG12.GPIO_Label=IMU_MISO
PG12.Signal=SPI6_MISO
PG13.GPIO_Label=IMU_SCK
PG13.Signal=SPI6_SCK
PG14.GPIO_Label=IMU_MOSI
PG14.Signal=SPI6_MOSI
PG5.GPIO_Label=STATUS_LED
PG5.Signal=GPIO_Output
PG9.GPIO_Label=IMU_INT2
PG9.Signal=GPIO_Input
PH0/OSC_IN.Signal=RCC_OSC_IN
PH1/OSC_OUT.Signal=RCC_OSC_OUT
PH2.GPIO_Label=GPS_INT
PH2.Signal=GPIO_Input
PH3.GPIO_Label=MEM_nCS
PH3.Signal=GPIO_Output
PI11.GPIO_Label=RADIO_nRST
PI11.Signal=GPIO_Output

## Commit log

2024-02-07 Rename files
    [rocket2-ecu.kicad_pcb, rocket2-ecu.kicad_sch]
2024-02-07 Add PCB outline
    [rocket2-ecu.kicad_pcb]
2024-03-06 Initial setup
    [PowerReg.kicad_sch, pt.kicad_sch, rocket2-battery.kicad_sch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]
2024-03-11 Lots of cleanup and updates; Waiting on PR approval for GPS filter
    [PowerReg.kicad_sch, ecu_stm32.kicad_sch, eve_gps.kicad_sch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]
2024-03-24 changed usb-c, re-named and added some pins
    [ecu_stm32.kicad_sch, rocket2-battery.kicad_sch, rocket2-ecu.kicad_sch]
2024-03-26 fixes based on REDs testing
    [rocket2-battery.kicad_sch]
2024-03-30 added pin assignments to components on existing schematic
    [ecu_stm32.kicad_sch, rocket2-battery.kicad_sch, rocket2-ecu.kicad_sch]
2024-05-16 Updated so only STM pins left really
    [PowerReg.kicad_sch, ecu_stm32.kicad_sch, pt.kicad_sch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]
2024-05-22 added capacitors and resolved all comments
    [PowerReg.kicad_sch, ecu_stm32.kicad_sch, eve_gps.kicad_sch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]
2024-05-24 added oscillator
    [ecu_stm32.kicad_sch]
2024-05-25 fixed somwe stuff
    [ecu_stm32.kicad_sch]
2024-05-26 added flash memory and ldos
    [PowerReg.kicad_sch, ecu_stm32.kicad_sch, rocket2-ecu.kicad_sch]
2024-05-27 Added stat sense in REDs; kicad V8.01
    [PowerReg.kicad_sch, ecu_stm32.kicad_sch, eve_gps.kicad_sch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]
2024-06-07 8.02 Update; Also changed VRMs and added some notes
    [PowerReg.kicad_sch, ecu_stm32.kicad_sch, eve_gps.kicad_sch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]
2024-10-30 ECU essentially reviewable
    [ECU_Memory.kicad_sch, ECU_Radios.kicad_sch, PowerReg.kicad_sch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]
2024-10-30 Removed temp files
    [ecu_stm32_BACKUP_86.kicad_sch, ecu_stm32_BASE_86.kicad_sch, ecu_stm32_LOCAL_86.kicad_sch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]
2024-11-16 addressed PR comments
    [ECU_Memory.kicad_sch, ECU_Radios.kicad_sch, PowerReg.kicad_sch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]
2024-11-30 Updated schematic with IOC
    [ECU_Radios.kicad_sch, ecu_stm32.kicad_sch, pt.kicad_sch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]
2024-12-02 Moved PTs to ADC pins
    [ecu_stm32.kicad_sch]
2024-12-03 Assigned almost all footprints
    [ECU_Memory.kicad_sch, ECU_Radios.kicad_sch, PowerReg.kicad_sch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]
2024-12-05 Started layout
    [rocket2-battery.kicad_sch, rocket2-ecu.kicad_pcb]
2024-12-17 Started putting it all together
    [rocket2-ecu.kicad_pcb]
2024-12-19 More layout updates
    [rocket2-ecu.kicad_pcb]
2024-12-23 Replaced Regs
    [PowerReg.kicad_sch, ecu_stm32.kicad_sch, rocket2-battery.kicad_sch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]
2024-12-23 made reg circuits
    [rocket2-ecu.kicad_pcb]
2024-12-26 All parts on board, starting routing
    [rocket2-battery.kicad_sch]
2024-12-27 Lots of routing
    [ecu_stm32.kicad_sch, rocket2-battery.kicad_sch]
2024-12-27 More routing, only GPS and REDS radio left
    [ecu_stm32.kicad_sch]
2024-12-27 Finished layout
    [PowerReg.kicad_sch, rocket2-battery.kicad_sch]
2024-12-27 Added mounting holes
    [rocket2-ecu.kicad_sch]
2024-12-30 Updated with Daniels suggestions
    [ecu_stm32.kicad_sch, rocket2-ecu.kicad_sch]
2025-01-01 Added buzzer
    [rocket2-ecu.kicad_sch]
2025-01-07 resolved continuous ground issues
2025-01-08 new BOM
    [ECU_Memory.kicad_sch, ECU_Radios.kicad_sch, PowerReg.kicad_sch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]
2025-01-09 Addressed comments; See issue for notes
    [eve_gps.kicad_sch, rocket2-battery.kicad_sch, solenoid.kicad_sch]
2025-01-09 Fixed groundstiching and pad sizes
2025-01-10 Fully up to date
    [ecu_stm32.kicad_sch]
2025-11-13 REDS updated with diodes and hierarchy to main micro
    [ECU_Memory.kicad_sch, ECU_Radios.kicad_sch, PowerReg.kicad_sch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]
2025-11-13 Updated REDS for working
    [rocket2-battery.kicad_sch, rocket2-ecu.kicad_sch]
2025-11-16 Added power sense to rocket2-battery with voltage follower, added +1 solenoids and PT circuit, made new gx connectors
    [pt.kicad_sch, rocket2-battery.kicad_sch, rocket2-ecu.kicad_sch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]
2025-11-16 moved from bmm150 to bmm350
    [ecu_stm32.kicad_sch, rocket2-ecu.kicad_sch]
2025-11-16 idk what I changed tbh
    [ECU_Memory.kicad_sch, rocket2-ecu.kicad_pcb]
2025-11-17 Component placement halfway done
    [PowerReg.kicad_sch, rocket2-battery.kicad_sch, rocket2-ecu.kicad_pcb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]
2025-11-20 Placed radios
    [rocket2-ecu.kicad_pcb, rocket2-ecu.step]
2025-11-21 3/4 DC-DC converters done
    [ECU_Radios.kicad_sch, pt.kicad_sch, rocket2-ecu.kicad_pcb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]
2025-11-22 power connectors done
    [rocket2-ecu.kicad_pcb, rocket2-ecu.kicad_sch]
2025-11-22 ALMOST DONE WITH PLACEMENT
    [rocket2-ecu.kicad_pcb]
2025-11-22 more routing, 25% done
    [ecu_stm32.kicad_sch, rocket2-battery.kicad_sch]
2025-11-24 layout done
    [ECU_Radios.kicad_sch, ecu_stm32.kicad_sch, eve_gps.kicad_sch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]
2025-12-01 Deleted 5V, edited LPFs on TCs and PTs
    [PowerReg.kicad_sch, pt.kicad_sch, rocket2-ecu.kicad_sch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]
2025-12-02 updating 3d cad, not done
    [rocket2-ecu.kicad_sch]
2025-12-02 CAD almost done, missing gx connectors
2025-12-02 CAD completely done
2025-12-12 version in PCBway 12/12/2025
    [ECU_Radios.kicad_sch, pt.kicad_sch, rocket2-battery.kicad_sch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]
2025-12-14 added .ioc file
    [ecu_stm32.kicad_sch]
2025-12-26 added some production files
    [PowerReg.kicad_sch, pt.kicad_sch, rocket2-battery.kicad_sch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]
2026-01-12 changed charging circuit for Insta360, gonna send in now on JLCPCB
    [ECU_Memory.kicad_sch, ECU_Radios.kicad_sch, PowerReg.kicad_sch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]
2026-04-16 added ecu adapter board submodule
2026-04-19 fixing docs sruture
    [pt.kicad_sch]
2026-04-28 added bring-up test plan and current ecu hardware bring-up updates
    [rocket2-ecu.kicad_sch]
2026-04-30 Reformatted file structure
    [ECU_Memory.kicad_sch, ECU_Radios.kicad_sch, PowerReg.kicad_sch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]
2026-05-05 fixed connector system description and updated bring-up log
